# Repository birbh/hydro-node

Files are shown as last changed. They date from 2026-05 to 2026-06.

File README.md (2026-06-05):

# hydro-node

Hydronode is an ESP32 based smart irrigation and plant monitoring system which is designed to automate watering using industrial grade solenoid feed valve.

hydronode

## What is this project??
This project is a self thinking, internet connected plant care and monitoring system that bridges the gap between hardware and earth. Unlike some DIY kits which rely on cheap and low quality pump, this project uses heavy duty solenoid water feed valve which was designed for water purifiers. The moisture sensor continuously tracks the soil vitals and serves local interface right from microcontroller. 

## Why is this unique?
It is unique because it has dual mode execution : it uses hardware logic to dynamically protect plants from dry soil allowing instant,secure watering process for the plants and also can be controlled from mobilephone on the network.

## Story behind this:
I have a Kent RO purifier in my home. Recently the water from RO was leaking from the pipe and we called for support and a person came and changed a feed valve and charged us 10$ just for a part. I was curious about the part and after a hour of research I found that it was a feed valve which works on the principle of electromagnet. Then I started searching why it was leaking and what was the problem and found many reasons. Then I thought 'Why not open it and try to fix?？'. Then I opened it using screwdriver and foumd that the rubber in its bottom was slightly misplaced and some water dirts were deposited in the Base of valve.

So seeing this I cleaned the valve and repositioned the rubber in the bottom. Then I again tested it and say what? It worked and now was good as new. Then I started thinking of using on a project like this which would be lifesaving for many farmers and even in our home use. Then i started brainstorming and came to an idea of making an IOT project with this. 

## Why did I make it?

The main motive of Hydronode is that it solves major issues such as:
- frustrating unreliability of a hobbyist irrigation setups and anexity of leaving plants unattended.
- in standard low quality valve small plastics clog easily and lack mechanical seating needed for clean water distribution by using a robust solenoid valve, I want to create a system that handles direct water line pressures safely without any leaking.

## How to build it?
### Prepare the enclosure:

1. 3D Print the enclosure and lid as shown in CAD model.(OR buy a waterproof box)
2. If you buy a waterproof box, create mounts for:
    - USB charging module
    - Solar mount
    - OLED display
    - Battery holder
    - Relay holder
    - Boost converter
    - ESP32 mount
    - Hinge mount
    - Wire holes 
    - Switch mount
3. Secure all components using screws, standoffs or adhesive mounts
4. Install internal electronics and mount them as follows:
    - ESP32 Devkit V1
    - Relay module
    - Breadboard(use the dedicated tape in the breadboard to mount it)
    - TP4056 Charging Module(use my custom part in CAD for this)
    - MT3608 Boost Converter
    - 18650 battery holder
    - Oled display
    - Solar panel
    - Switch

    (Note: ensure that the electronics are secured and no conductive parts are touching each other)
    - Install the hinge model and mount it with screws as in the CAD.
5. Assembling the water system:
    - Connect the plumbing as shown in the CAD:
        - WATER SOURCE -> SOLENOID VALVE -> PLANT POT
    - The valve should be installed inline between the water source and the plant irrigation pipe.
    - Use 1/4" inch RO tubing and compatible connectors to prevent leaks
    - Install soil moisture sensor vertically into the soil near plant roots
    - Avoid placing the sensor directly beside the water outlet, as this may produce inaccurate recordings
    - Connect the relay and valve with 24V DC adapter
    - Install a 1N4007 flyback diode across the valve terminals to prevent it from voltage spikes.
6. Configure the power system:
    - First set the MT3608 output to exactly 5V using the multimeter
    - Connect the solar panel to TP4056 charging module
    - Then TP4056 module to MT3608 boost converter
    - Then MT3608 boost converter to ESP32 usb port
7. Upload the firmware to ESP32 and update the wifi credentials in firmware
8. Test the system verifying all the components of the system
(be sure to set the moisture sensor values according to your environmental condition)

### Final assembly:
After successful testing:
- Organize wiring neatly
- close the enclosure
- connect the permanent water source
- seal cable openings to prevent short circuits
- ensure the electronics never come in contact with water

## How to use it??

1. First, power the esp32 and connect the valve system properly.
2. Upload the firmware using arduino ide.
3. Connect the ESP32 to your wifi network by editing a part in firmware:
```
const char* ssid="hydronode";
const char* password="soil@123";

```
4. Open serial monitor in your pc and copy the ESP32 IP address. eg: 192.168.1.5
5. Open the IP address in your browser while connected to the same wifi.
6. Use the dashboard to:
- monitor soil moisture
- enable AUTO mode
- manually control watering
7. Place the sensor into soil and connect the valve to the water line.

(note: hydronode will also automatically water plants when soil becomes dry.)

## Features:
- Realtime soil moisture monitoring
- Auto irrigation logic
- Manual watering from mobile
- ESP32 Wifi web dashboard
- Solar powered green energy system
- Industrial grade 24V solenoid valve
- Low cost modular design

## Web Dashboard:

HydroNode includes a built in mobile friendly web interface hosted directly on ESP32.
This dashboard allows user to:

- Monitor soil moisture percentage
- Check valve status
- Enable auto irrigation mode
- Manually turn watering ON and OFF
- No external mobile app or cloud service required

## Auto irrigation logic:
| Moisture level | Action |
| --- | --- |
| 0-30% | Start Watering | 
| 30-60% | Maintain Normal state | 
| 60-100% | Stop Watering | 

## Power System:
The ESP32 is powered using a rechaargable 18650 battery combined with solar assisted charging.
The valve system uses dedicated 24V adapter ro safely handle higher current requirements.
This hybrid power architecture improves efficiency portability and long term reliability.

## CAD:
### SS:

Screenshot 2026-05-31 at 4 35 32 PM
Screenshot 2026-05-31 at 4 39 03 PM
Screenshot 2026-05-31 at 4 37 30 PM
Screenshot 2026-05-31 at 4 39 58 PM

### Links:
Onshape: [Hydronode](https://cad.onshape.com/documents/a54d490bebb072f24616d72a/w/eb742d430f9342788aa9bc21/e/95767b8b5a8d5928ced10f44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)

## Circuit:
### SS:
solar+charging
esp-circuit

### Links:
Wokwi: [esp-circuit](https://wokwi.com/projects/464828058447249409)

Tinkercad:  [solar and charging](https://www.tinkercad.com/things/fsAw2kbm3HE-solar-hydronode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)

### Pin mapping:
### Soil moisture sensor:
| Component | ESP32 pin |
| --- | --- |
| Soil Moisture sensor(AOUT) | GPIO34 | 
| VCC | 3V3 |
| GND | GND |

### Relay module:
| Relay pin | Connection |
| --- | --- |
| VCC | VIN(5V) | 
| GND | GND | 
| IN | GPIO26 | 
| NO | Solenoid Valve(+ve) |
| COM | 24V Adapter(+ve) |

### OLED Pin:
| OLED | ESP32 pin |
| --- | --- |
| VCC | 3V3 |
| GND | GND |
| OLED SDA | GPIO21 | 
| OLED SCL | GPIO22 | 

### Solenoid valve:
| Solenoid | Connection | 1N4007 diode |
| --- | --- | --- |
| Solenoid Valve(+ve) | Relay(NO) | Stripe side |
| Solenoid Valve(-ve) | 24V Adapter(-ve) | Non-stripe side |

### 24V adapter:
| Adapter | Connection |
| --- | --- |
| 24V Adapter(+ve) | Relay(COM) |
| 24V Adapter(-ve) | Solenoid Valve(-ve) |

### Charging and boost:
### TP4056 charging module:
| Module | Connection |
| --- | --- |
| B+ | 3.6V li-ion battery(+ve) |
| B- | 3.6V li-ion battery(-ve) |
| IN+ | Solar panel(+ve) |
| IN- | Solar panel(-ve) |
| OUT+ | MT3608 Boost(VIN+) |
| OUT- | MT3608 Boost(VIN-) |

### MT3608 Boost converter(set to 5V):
| Module | Connection |
| --- | --- |
| VIN+ | TP4056(OUT+) |
| VIN- | TP4056(OUT-) |
| VOUT+ and VOUT- | Join to ESP32 usb port wires |

## Initial coponents(planned):

- ESP32 DevKit V1
- Capacitive soil moisture sensor v1.2 
- 1 Channel Relay Module
- FPD-180K80-DC24V Solenoid Feed Valve
- 24V 0.5A DC Power Supply Adapter 
- 1N4007 diode
- Breadboard
- Pipe ( 1/4" Size) for purifiers
- Multimeter(Optional)
- Oled display(Optional)
- Waterproof Box
- Solar Panel 70x70mm, 4V, 100mA
- MT3608 Boost Converter 
- TP4056 Charger Module 
- Lithium-ion battery 18650
- 18650 Series Batteries Holder

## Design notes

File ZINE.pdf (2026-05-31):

# hydronode

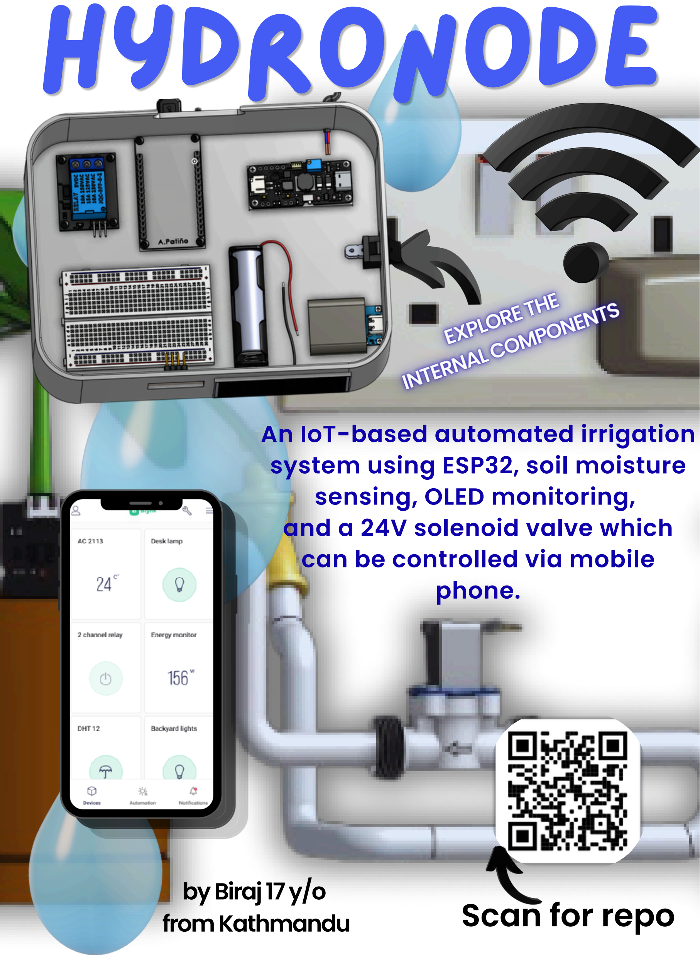
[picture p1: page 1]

EXPLORETHE
INTERNALCOMPONENTS

## Scan for repo

An IoT-based automated irrigation system using ESP32, soil moisture sensing, OLED monitoring,
and a 24V solenoid valve which can be controlled via mobile phone.

byBiraj17y/o
fromKathmandu

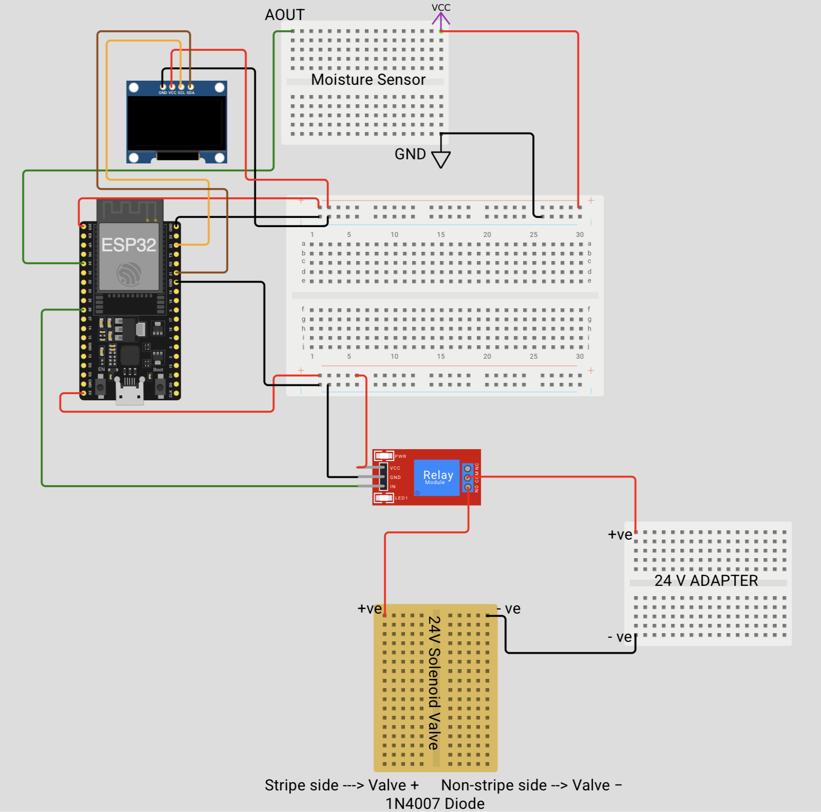
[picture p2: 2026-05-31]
Circuit/esp-circuit.png

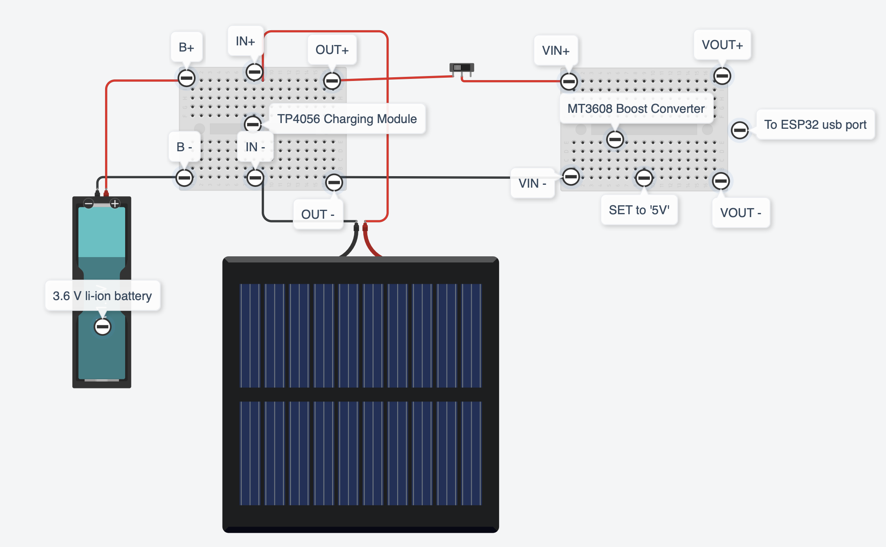
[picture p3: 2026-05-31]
Circuit/solar+charging.png

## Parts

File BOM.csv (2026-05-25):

Item | Price | Link | Quantity
ESP32 DevKit V1 | ~7$ | https://shortlink.uk/1vkuV | 1
Capacitive soil moisture sensor v1.2 | 5$ | https://shorturl.at/3VSwV | 1
1 Channel Relay Module | 2$-3$ | https://shorturl.at/jhp8j | 1
FPD-180K80-DC24V Solenoid Feed Valve | $8 | https://shorturl.at/AlwTq | 1
24V 0.5A DC Power Supply Adapter | $10 | https://shorturl.at/P9sPZ | 1
1N4007 diode | $1 | https://shorturl.at/y7W71 | Pack
Breadboard | $10 | https://l1nk.dev/uzbsl38 | 1
Jumper wires | $8 | https://l1nk.dev/i9meakx | Pack
Normal wires | $4 | https://shorturl.at/ygMDc | Pack
Usb cable for ESP32 | $2 | https://shorturl.at/VlY7y | 1
Pipe ( 1/4" Size) for purifiers | $3-$4 | https://shorturl.at/fXBLP | 1
Multimeter(Optional) | $6 | https://shorturl.at/YAGk5 | 1
Oled display(Optional) | $6 | https://shorturl.at/uvh9P | 1
Waterproof Box | $7 | https://h1.nu/1p-2Y | 1
Solar Panel 70x70mm, 4V, 100mA | $4 | https://shorturl.at/NjqiL | 1
MT3608 Boost Converter | $6 | https://shorturl.at/b5so8 | 1
TP4056 Charger Module | $6 | https://shorturl.at/bXgLx | 1
Lithium-ion battery 18650 | $2 | https://shorturl.at/1rUtV | 1
18650 Series Batteries Holder | $2 | https://shorturl.at/PRn9Q | 1
Total | ~$92

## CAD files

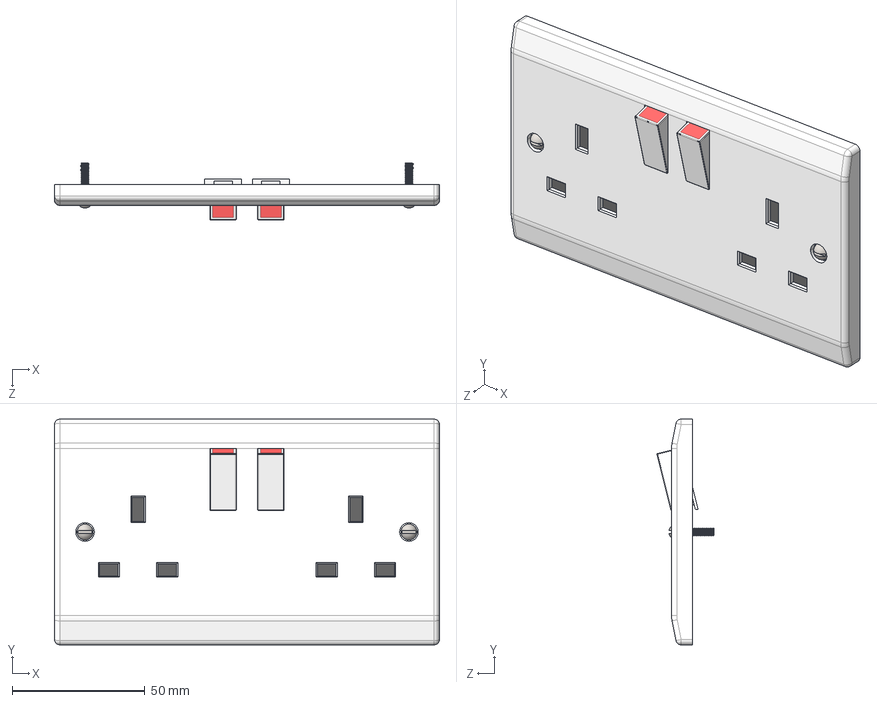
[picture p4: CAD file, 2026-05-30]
CAD/parts/Assembled-Mains-Plug-Socket.STEP
145.0 x 85.0 x 21.5 mm
Switch x 2
Base Plate
Screw x 2
Black Cover x 2

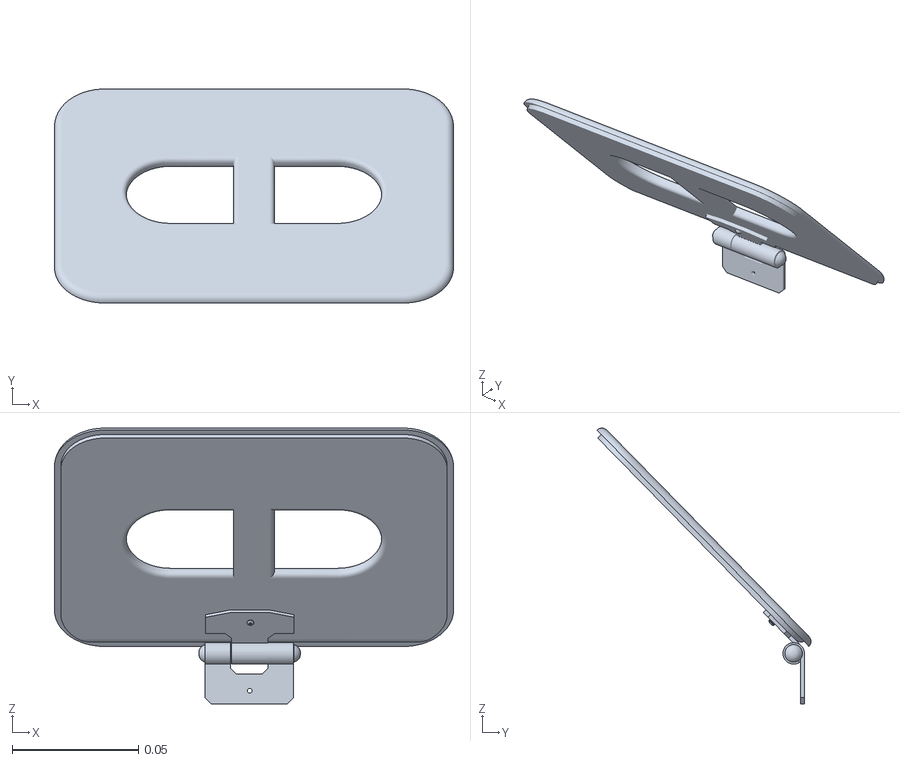
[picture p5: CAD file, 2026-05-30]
CAD/Assemblies/hinge_modal.stl
0.158 x 0.0848 x 0.109

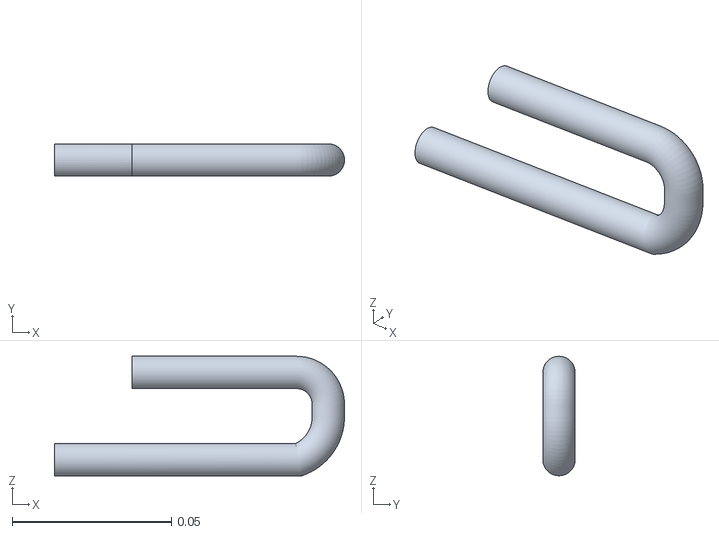
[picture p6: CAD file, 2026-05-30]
CAD/parts/Pipes/Pipe in.stl
0.0909 x 0.0102 x 0.0375

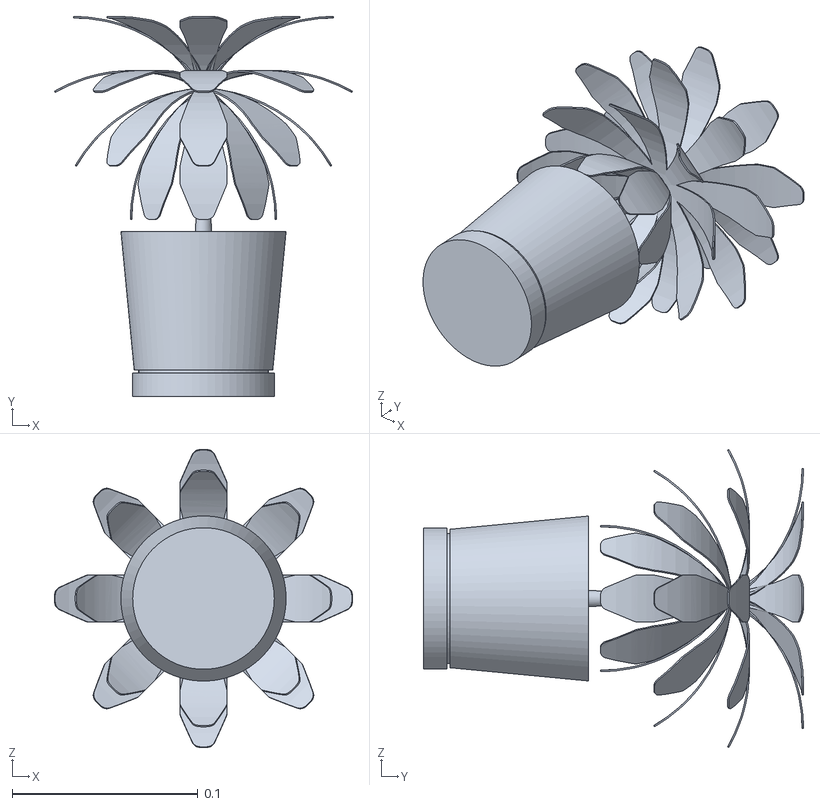
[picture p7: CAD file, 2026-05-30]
CAD/parts/plant.stl
0.16 x 0.204 x 0.16

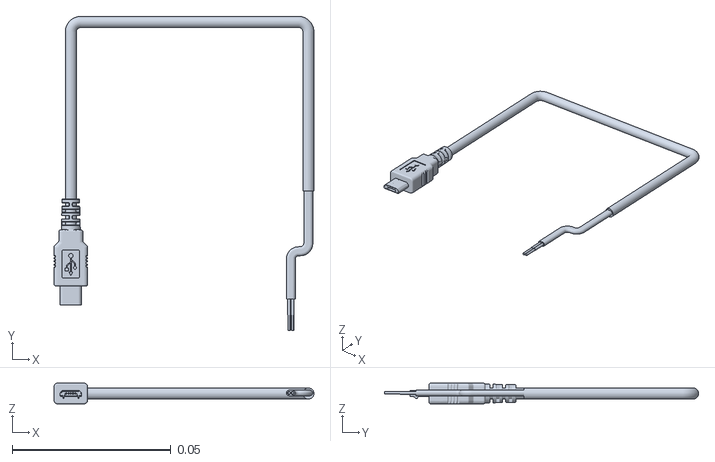
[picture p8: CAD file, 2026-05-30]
CAD/Assemblies/Micro b to boost.stl
0.0819 x 0.099 x 0.0066

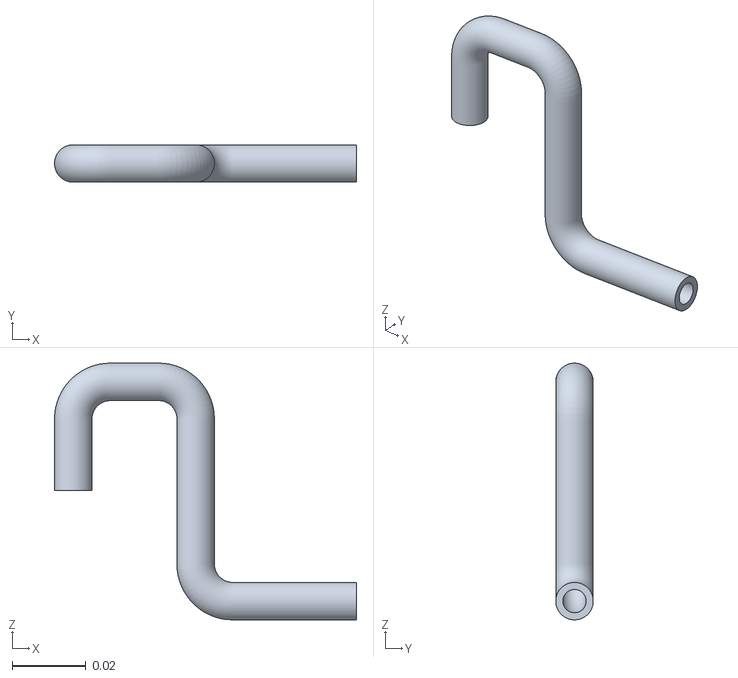
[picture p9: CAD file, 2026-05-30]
CAD/parts/Pipes/Pipe out.stl
0.0817 x 0.0101 x 0.0694

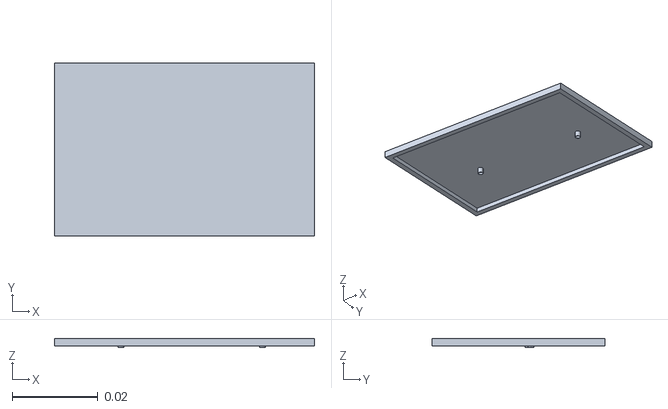
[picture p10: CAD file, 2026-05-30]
CAD/parts/SolarPV.stl
0.0605 x 0.0402 x 0.0021

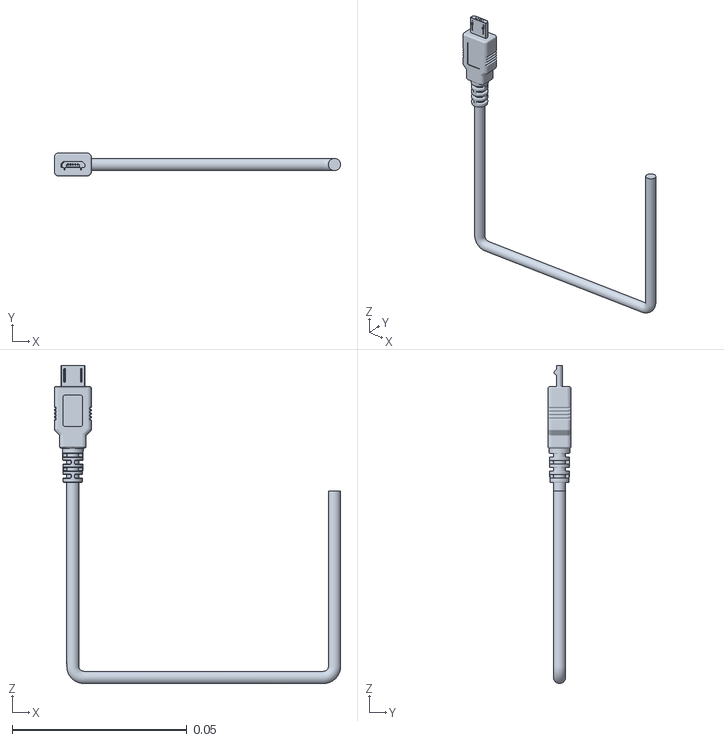
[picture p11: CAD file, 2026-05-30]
CAD/parts/Micro-USB-Plug.stl
0.0819 x 0.0066 x 0.0909

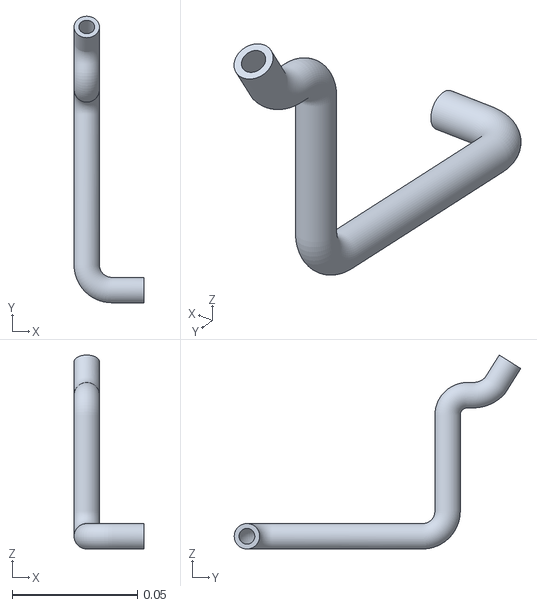
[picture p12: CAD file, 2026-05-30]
CAD/parts/Pipes/TAP pipe.stl
0.0279 x 0.114 x 0.0774

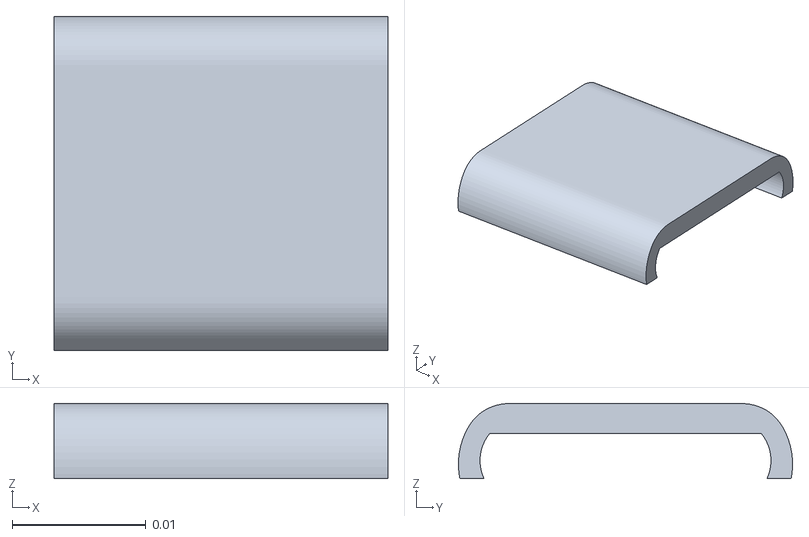
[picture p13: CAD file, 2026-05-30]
CAD/parts/mount_tp4056.stl
0.025 x 0.025 x 0.00562

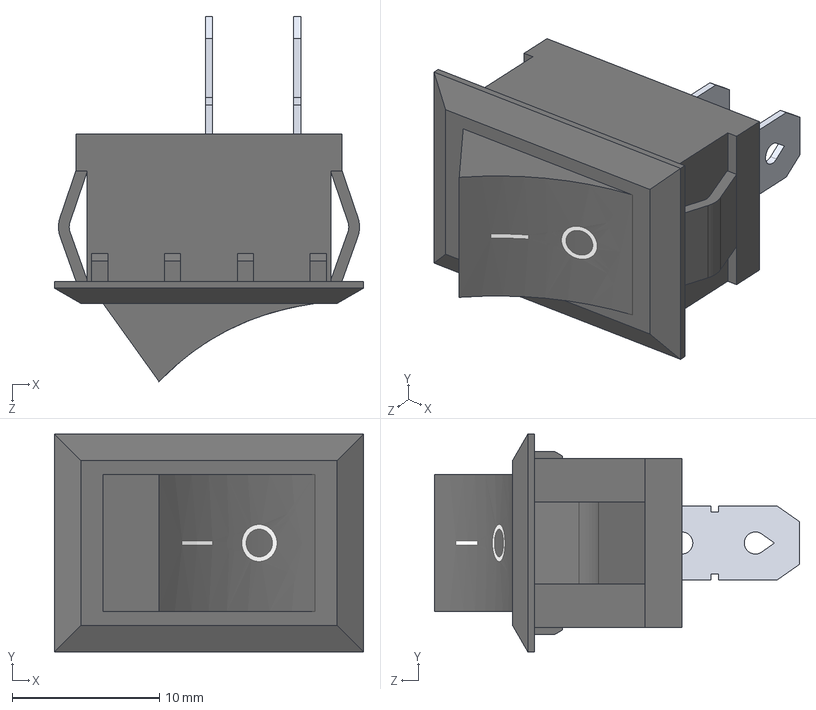
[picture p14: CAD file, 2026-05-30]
CAD/parts/RockerSwitch.STEP
21.0 x 14.8 x 24.8 mm

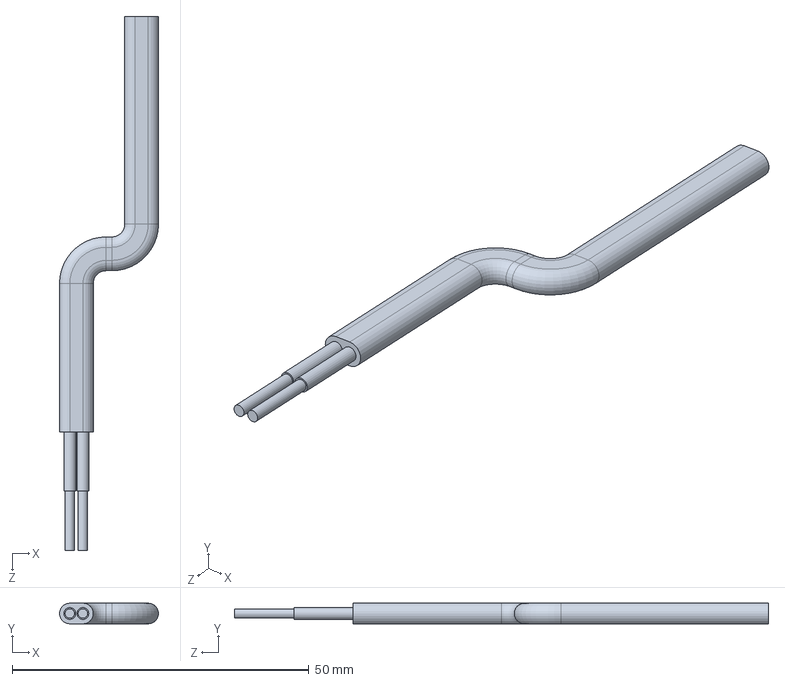
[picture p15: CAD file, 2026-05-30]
CAD/parts/wire simple.SLDPRT
16.7 x 3.50 x 90.0 mm

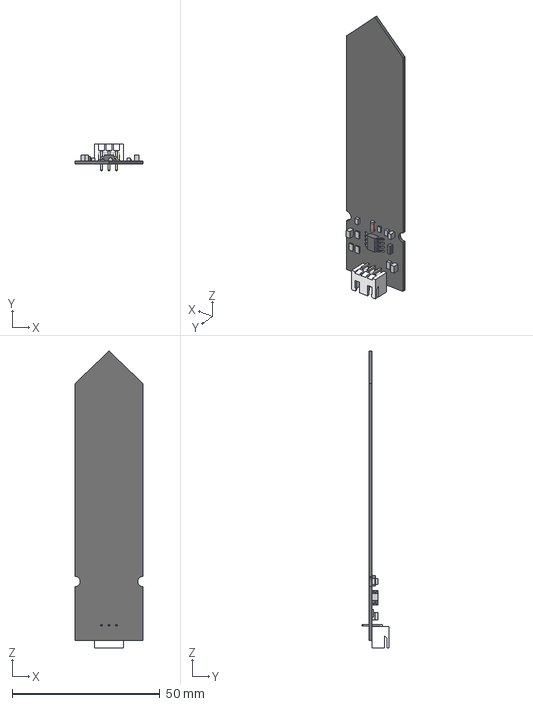
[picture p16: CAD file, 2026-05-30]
CAD/parts/Moisture Sensor - 3D.step
23.0 x 9.22 x 100.5 mm

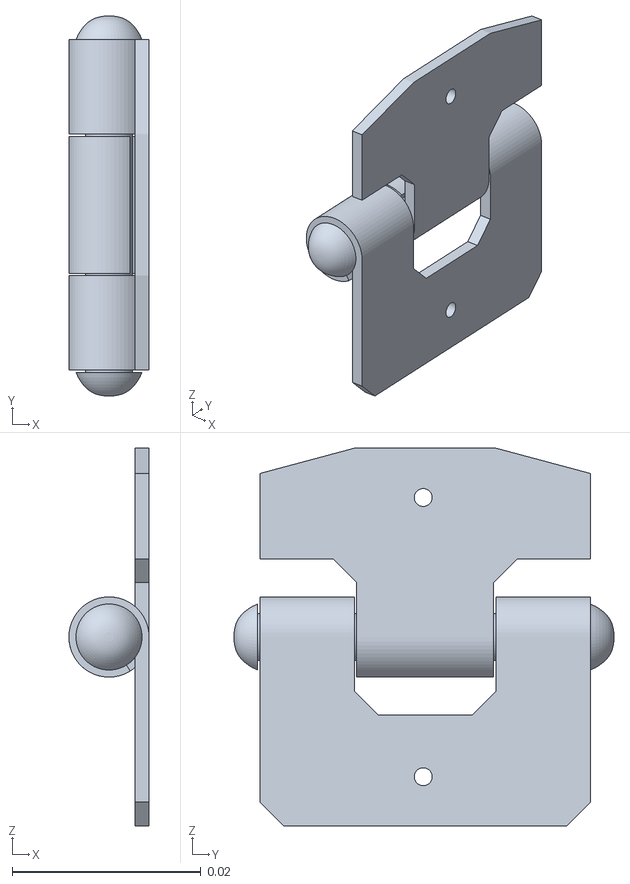
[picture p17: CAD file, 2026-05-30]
CAD/parts/hinge-485.stl
0.0085 x 0.0403 x 0.04

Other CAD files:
CAD/parts/OLED TEMU 0.96 in.stp
CAD/parts/box.stl
CAD/parts/Cell-18650.STEP
CAD/parts/watertapa.igs
CAD/parts/18650-Battery-Holder.STEP
CAD/parts/mount_boost.stl
CAD/parts/screws/M2-8_torx.stl
CAD/parts/screws/M2-8_torx_minn.stl
CAD/parts/screws/M2-8_torx_small.stl
CAD/parts/screws/big scc.stl
CAD/parts/screws/med scc.stl
CAD/parts/screws/small scc.stl

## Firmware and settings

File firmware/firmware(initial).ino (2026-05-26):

#include <WiFi.h>
#include <Adafruit_GFX.h>
#include <Adafruit_SSD1306.h>
#include <Wire.h>
#include <WebServer.h>

#define width 128
#define height 64

Adafruit_SSD1306 display(width, height, &Wire, -1);

WebServer server(80);

// wifi info.

const char* ssid="hydronode";
const char* password="soil@123";


// pins
#define soil_moisture_sensor_pin 34
#define relay_in_pin 26

//req. variables
bool valve_state = false;
bool auto_esp= true;
int moistureper=0;

//soil values(changable acc to your sensor)
int dry_soil=3500;
int wet_soil=1500;

//time see
unsigned long prevmillis=0;
const long interval=2000;



//html page for web server
String webpage(){
String page=R"rawliteral(
<!DOCTYPE html>
<html>
<head>
    <title>HydroNode</title>
    <meta name="viewport" content="width=device-width, initial-scale=1">
    <style>
        body { 
            font-family: Arial, sans-serif;
            background: #3a3838;
            color: white;
            text-align: center;
            padding: 15px;
        }
        .container {
            background: #2a2828;
            padding: 20px;
            border-radius: 20px;
            margin: auto;
            max-width: 400px;
            box-shadow: 0 0 20px rgba(0, 0, 0, 0.4);
            
        }
        h1{
            color: #4CAF50;
        }
        .data{
            font-size: 22px;
            margin:15px;
        }
        button{
            width: 150px;
            padding: 15px;
            margin:10px;
            border: none;
            border-radius: 15px;
            font-size: 16px;
            cursor: pointer;
        }
        .on{
            background: #4ca7af;
            color: white;
        }
        .off{
            background: #c53b31;
            color: white;
        }
        .mode{
            background: #439045;
            color: white;
        }

    </style>
    </head>
<body>
<div class="container">
    <h1>HydroNode</h1>

    <div class="data">
    Moisture: )rawliteral";
    page+= moistureper;
    page+=R"rawliteral(%</div>
    
    <div class="data">
    Valve: )rawliteral";
    page+= valve_state ? "ON" : "OFF";
    page+=R"rawliteral(</div>
    <a href="/on">
        <button class="on">Water ON</button>
    </a>
    <a href="/off">
        <button class="off">Water OFF</button>
    </a>
    <a href="/auto">
        <button class="mode">Auto Mode</button>
    </a>
    <a href="/manual">
        <button class="mode">Manual Mode</button>
    </a>
</div>
</body>
</html>)rawliteral";
return page;
}


// handlers
void handleroot(){
    server.send(200,"text/html",webpage());  
}
void handleon(){
    valve_state = true;
    digitalWrite(relay_in_pin, LOW);
    server.sendHeader("Location", "/");
    server.send(303);
}
void handleoff(){
    valve_state=false;
    digitalWrite(relay_in_pin, HIGH);
    server.sendHeader("Location", "/");
    server.send(303);
}
void handleauto(){
    auto_esp= true;
    server.sendHeader("Location", "/");
    server.send(303);
}

void handlemanual(){
    auto_esp=false;
    server.sendHeader("Location", "/");
    server.send(303);
}


//moisturesensor read
void readmoisture(){
    int raw_value= analogRead(soil_moisture_sensor_pin);
    //calc %
    int moisturepercent=map(raw_value,dry_soil,wet_soil,0,100);
    moistureper= constrain(moisturepercent,0,100);
}

//auto watering

void auto_watering(){
    if (auto_esp){
        if(moistureper<30){
            valve_state= true;
            digitalWrite(relay_in_pin, LOW);
        }
        else if(moistureper>60){
            valve_state=false;
            digitalWrite(relay_in_pin, HIGH);

        }
    }
}

//oled 
void oleddisplay(){
    display.clearDisplay();
    display.setTextSize(1);
    display.setCursor(0,0);
    display.println("HydroNode");
    display.setCursor(0,16);
    display.print("Moisture: ");
    display.print(moistureper);
    display.print("%");

    display.setCursor(0,32);
    display.print("Valve: ");
    if (valve_state){
        display.print("ON");
    }
    else{
        display.println("OFF");
    }

    display.setCursor(0,48);
    display.println("MODE");
    
    if (auto_esp){
        display.print("AUTO");
    }
    else{
        display.print("MANUAL");
    }
    display.display();

}

//setup 
void setup(){
    Serial.begin(115200);
    pinMode(relay_in_pin,OUTPUT);
    digitalWrite(relay_in_pin,HIGH);

    //oled init..
    Wire.begin(21,22);
    if (!display.begin(SSD1306_SWITCHCAPVCC,0x3C))
    {
        Serial.println("OLED Failed");
        while(true);
    }
    display.clearDisplay();
    display.display();

    // wifi ini..
    WiFi.begin(ssid,password);
    display.setTextSize(1);
    display.setTextColor(WHITE);

    while (WiFi.status()!= WL_CONNECTED)
    {
        delay(1000);
        display.clearDisplay();
        display.setCursor(0,0);
        display.println("Connecting WiFi....");
        display.display();
    }
    
    // wifi conn...
    display.clearDisplay();
    display.setCursor(0,0);
    display.println("WiFi Connected");
    display.println("");
    display.println(WiFi.localIP());
    display.display();
    Serial.println(WiFi.localIP());

    //web route
    server.on("/",handleroot);
    server.on("/on",handleon);
    server.on("/off",handleoff);
    server.on("/auto",handleauto);
    server.on("/manual",handlemanual);
    server.begin();



}


//loop
void loop(){
    server.handleClient();

    unsigned long millisnow=millis();
    if(millisnow- prevmillis>=interval){
        prevmillis=millisnow;
    readmoisture();
    auto_watering();
    oleddisplay();
    }
}

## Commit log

2026-05-20 BOM update
    [BOM.csv]
2026-05-25 Update BOM, README, and add initial firmware code
    [BOM.csv]
2026-05-30 update 3d files
    [18650 Battery Holder.STEP, Assembled Mains Plug Socket.STEP, Cell 18650.STEP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]
2026-05-31 update readme and added ZINE and circuit files
    [Solar-hydronode.brd]
2026-05-31 fix- file names
    [18650-Battery-Holder.STEP, Assembled-Mains-Plug-Socket.STEP, Cell-18650.STEP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]
